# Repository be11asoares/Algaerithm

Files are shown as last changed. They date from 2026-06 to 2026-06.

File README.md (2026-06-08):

# Algaerithm — Build Your Own Pod

Algaerithm is a citizen-science river-monitoring project. A floating pod holds a
colony of microalgae (*Chlamydomonas*) in river water and watches how its colour
changes — greener water means a higher nutrient load. A small camera inside the
pod sends a photo to the cloud every few seconds, and those photos appear live on
the shared map at the project website.

This guide covers the **camera unit**: what to buy, how to flash it, and how to
get your pod's live image onto the shared Algaerithm map.

> One pod tells you about one stretch of water. A hundred pods start to tell you
> about a country. The more Guardians who join, the harder the data is to ignore.

---

## What you'll need

**Hardware**

- **Seeed Studio XIAO ESP32S3 Sense** — a tiny ESP32 board with a built-in
  camera and microSD slot. This is the board the reference pod uses.
  Search "XIAO ESP32S3 Sense" at the Seeed Studio store or any electronics
  retailer that stocks Seeed boards.
- A USB-C cable to flash and power it.
- (Optional) a microSD card if you also want to save full-resolution photos
  locally. The cloud upload works without one.
- A waterproof enclosure for the floating pod. Enclosure design is part of the
  wider project and not covered here.

**Software & accounts**

- The [Arduino IDE](https://www.arduino.cc/en/software) with ESP32 board support
  installed.
- A free [Adafruit IO](https://io.adafruit.com) account — this is the cloud
  service that receives your photos and makes them readable by the website.

---

## Step 1 — Set up Adafruit IO

Adafruit IO stores your latest photo in something called a **feed**. The website
reads that feed to show your image. You need two feeds.

1. Sign up at [io.adafruit.com](https://io.adafruit.com) (free).
2. Go to **Feeds → New Feed** and create two feeds. Name them simply:
   - `image-latest`
   - `last-photo-time`
3. **Check the feed _key_, not just the name.** Click into each feed and look at
   its **Key** (under the feed name or in its settings). The key is what the code
   and the website actually use. If you typed a dot or unusual characters in the
   name, Adafruit may turn them into something unexpected (for example a `.` can
   become `-dot-`). Make the keys clean: `image-latest` and `last-photo-time`.
4. Find your **username** (top-right account menu) and your **AIO Key**
   (the yellow key icon). You'll paste both into the code.

### ⚠️ Make both feeds Public — and keep them public

The website reads your feeds **without a password**, so they must be set to
**Public**. A public feed is still **read-only** to the world: anyone can see the
image, but only your AIO Key can upload to it. Your key stays private.

For each feed: open it → **Feed settings / privacy** → set **Public** → save.

**Confirm it worked.** Open this URL in a private/incognito window (logged out),
replacing the username and key with yours:

```
https://io.adafruit.com/api/v2/YOUR_USERNAME/feeds/image-latest
```

- If you see a block of text (JSON) including `"visibility":"public"` — you're
  good.
- If you see `{"error":"not found..."}` — the feed is still **private**. Set it
  to Public and check again.

> **This is the single most common reason a pod doesn't show up.** Adafruit's
> privacy setting can quietly flip back to private when you change other feed
> settings (especially toggling Feed History). After *any* change to a feed,
> re-check the incognito URL before relying on it.

### Turn Feed History off (recommended)

Your camera uploads constantly, and stored history fills your free quota fast.
In each feed's settings, turn **Feed History off** so it keeps only the latest
value. Then **re-check the Public setting** — toggling history can reset it.

---

## Step 2 — Flash the camera

1. Open the camera sketch (`camera_pod.ino`) in the Arduino IDE.
2. Select the **XIAO ESP32S3** board and the right port.
3. Fill in your details at the top of the sketch — these are the only lines you
   need to change:

   ```cpp
   // WiFi
   const char *ssid     = "YOUR_WIFI_NAME";
   const char *password = "YOUR_WIFI_PASSWORD";

   // Adafruit IO
   const char *aioUsername = "YOUR_USERNAME";
   const char *aioKey      = "YOUR_AIO_KEY";
   const char *aioFeedLatest = "image-latest";        // must match your feed KEY
   const char *aioFeedTime   = "last-photo-time";     // must match your feed KEY
   ```

4. Upload. Open the Serial Monitor at **115200 baud** to watch it connect.

You should see WiFi connect, then repeating lines like:

```
Capturing photo for Adafruit IO...
Upload size: 6020
Adafruit IO response code: 200
```

A **200** means success. Other codes:

- **404** — the feed key in your code doesn't match a feed on Adafruit, or the
  feed doesn't exist. Re-check the keys (Step 1.3).
- **-1** — the connection failed before completing, usually a memory squeeze from
  too large an image. Lower the resolution (see the `AIO_FRAME_SIZE` line in the
  sketch — `FRAMESIZE_HVGA` is a safe choice).

### A note on resolution

Bigger images look sharper but use more memory and can fail to upload. The sketch
uploads at a modest size on purpose. If uploads fail or the board crashes after a
few photos, step the resolution down. `FRAMESIZE_HVGA` (480×320) is a reliable
balance for the XIAO ESP32S3.

---

## Step 3 — Flash the AlgaeScope (spectrometer)

The AlgaeScope is the second board. It measures the algae's colour with an AS7341
spectral sensor and serves its own dashboard on your WiFi — no cloud account
needed for this part, and no separate app to install. The device *is* the app.

Wiring and the parts list (AS7341 sensor, white LED, ring lights, breadboard) are
on the [build page](https://algaerhythm.vercel.app/build.html). Once it's wired:

1. Open the AlgaeScope sketch (`algaescope.ino`) in the Arduino IDE.
2. Fill in your WiFi details at the top — these are the only lines to change:

   ```cpp
   const char* ssid      = "YOUR_WIFI_NAME";
   const char* password  = "YOUR_WIFI_PASSWORD";
   ```

3. Select the **XIAO ESP32S3** board and the right port, then upload.
4. Open the Serial Monitor at **115200 baud**. It connects to WiFi and prints the
   address where the dashboard is reachable.

### Reaching the dashboard

Once it's running, open a browser **on the same WiFi** and go to:

```
http://algaescope.local
```

If your network or device doesn't support `.local` addresses (some Android phones
and locked-down networks don't), use the numeric IP address the Serial Monitor
prints instead — it looks like `http://192.168.1.xx`.

The dashboard gives you live spectral readings, absorbance, the chlorophyll stress
ratio, a growth curve over time, grow-light control, and CSV export. Readings are
held in the device's memory while it's powered on.

> **Note:** reaching the device at `algaescope.local` relies on mDNS being enabled
> in the sketch. If you're using an older copy of the code, use the IP address from
> the Serial Monitor instead.

---

## Step 4 — Add your pod to the shared map

Once your camera is uploading and your feeds are public, you can have your pod
appear on the shared Algaerithm map alongside everyone else's.

**To add your pod, email us at b.soares0520251@arts.ac.uk** with the following:

| Field | Example | Notes |
|---|---|---|
| Guardian name | "Sam R." | A name we can credit on the map. |
| River / area | "River Lea · Hackney" | **Coarse area only** — your town or river reach, never your exact address. |
| Adafruit username | "sam_pods" | From your account menu. |
| Image feed key | "image-latest" | The feed **key**, exactly. |
| Timestamp feed key | "last-photo-time" | The feed **key**, exactly. |
| Both feeds public? | "Yes" | Confirm you've set both to Public (see Step 1) — we can't show your pod otherwise. |

We review each submission (mainly to confirm the feeds are public and the
location is coarse) and then add it to the map. Because we check by hand, there
may be a short wait — thanks for your patience.

> **Privacy:** please give only a coarse location — a river name and town or
> neighbourhood. The map deliberately never shows exact coordinates, so hosting a
> pod never reveals where you live.

---

## How it fits together (for the curious)

```
[ XIAO camera ]  --photo-->  [ Adafruit IO feed (public) ]  <--reads--  [ website ]
```

- The camera uploads a photo to your Adafruit feed every few seconds.
- Your feed is public, so the website can read its latest value from any browser.
- The website holds a list of all registered pods (`pods.json`) and shows a live
  card for each one.

No central server stores your images — the site reads each pod's public feed
directly. That keeps the whole thing free and simple to run.

---

## Common problems

| Symptom | Likely cause | Fix |
|---|---|-----|
| Pod doesn't appear on the site | Feed is private | Set feed to Public; confirm with the incognito URL (Step 1). |
| Serial shows `404` | Feed key mismatch | Match the code's feed names to the actual feed **keys** on Adafruit. |
| Serial shows `-1` | Image too large / low memory | Lower `AIO_FRAME_SIZE` to `FRAMESIZE_HVGA`. |
| Image shows on Adafruit but not the site | Page cached, or feed flipped private | Hard-refresh (Ctrl/Cmd+Shift+R); re-check Public setting. |
| Feed quota fills up | Feed History is on | Turn Feed History off, then re-confirm Public. |

---

## License

The code in this repository (the Arduino sketches and website) is released under
the **MIT License** — see the `LICENSE` file. You're free to use, modify, and
build on it; just keep the copyright notice.

The build documentation, designs, and project materials are shared under
**Creative Commons Attribution-ShareAlike (CC BY-SA 4.0)** — use and adapt them
freely, credit Algaerithm, and share your versions under the same terms.

*Algaerithm — MA Biodesign, Central Saint Martins, UAL.*

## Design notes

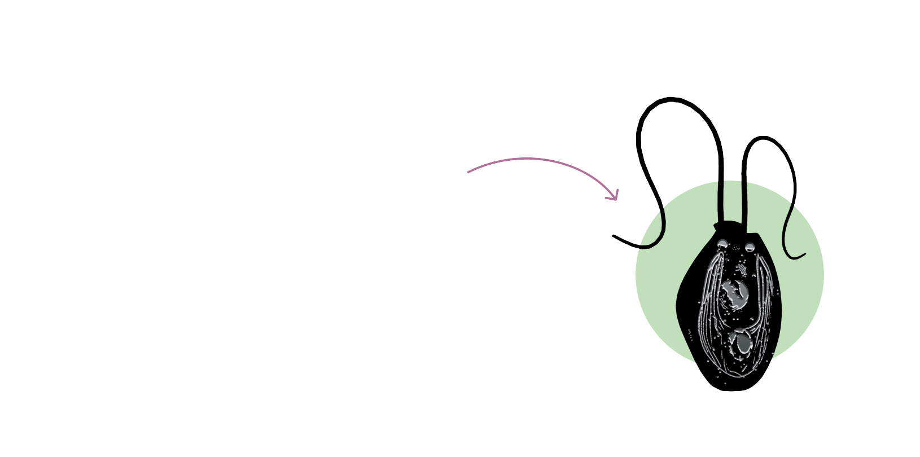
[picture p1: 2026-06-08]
chlamyy.png

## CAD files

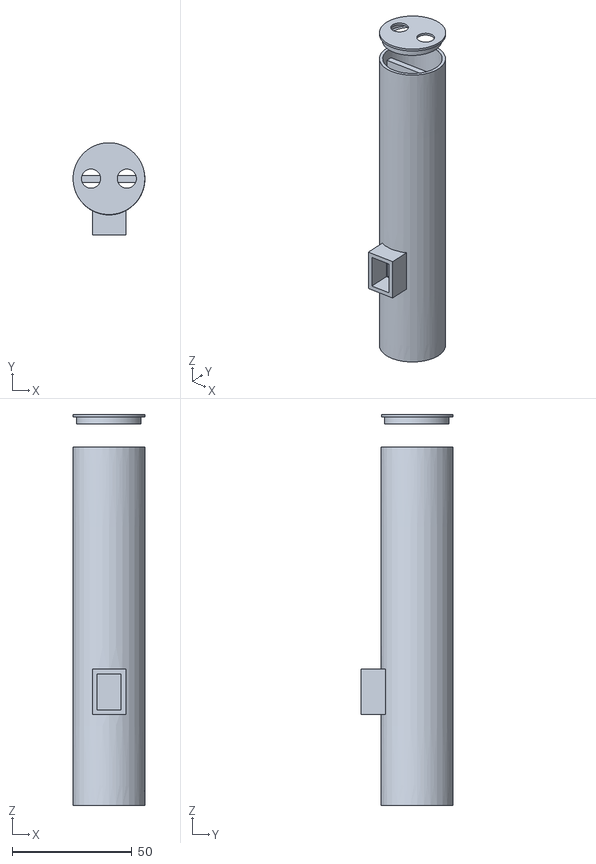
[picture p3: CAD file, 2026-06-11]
3d-files/column.stl
30.0 x 38.7 x 163.5

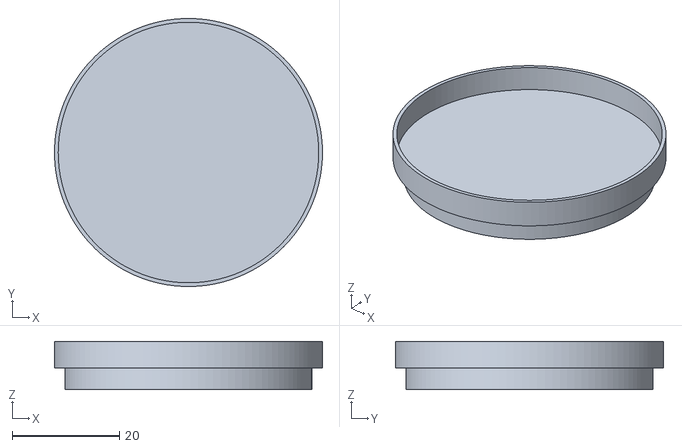
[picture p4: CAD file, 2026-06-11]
3d-files/led-support.stl
50.0 x 50.0 x 9.00

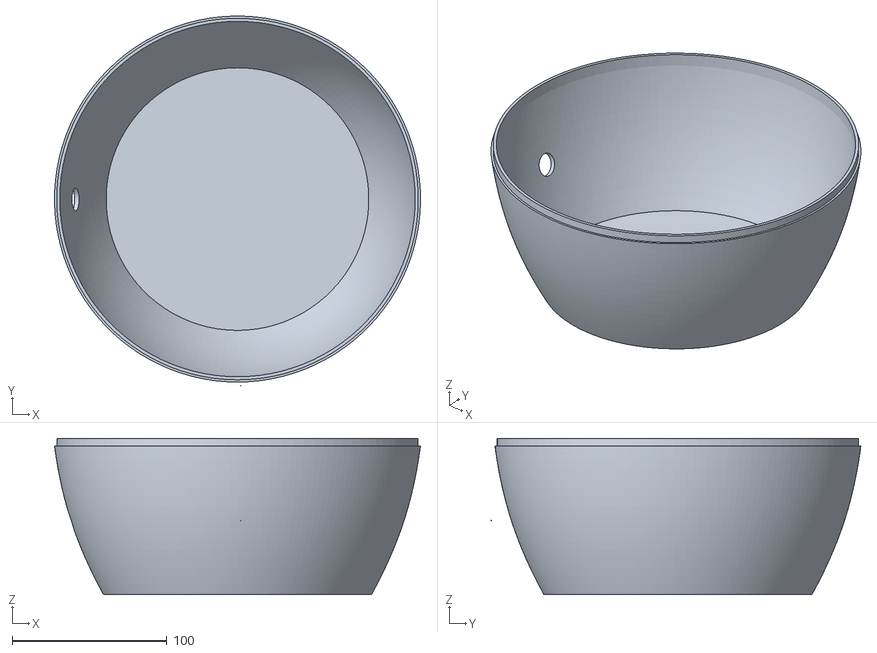
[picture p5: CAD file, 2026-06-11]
3d-files/base.stl
236.9 x 239.3 x 101.0

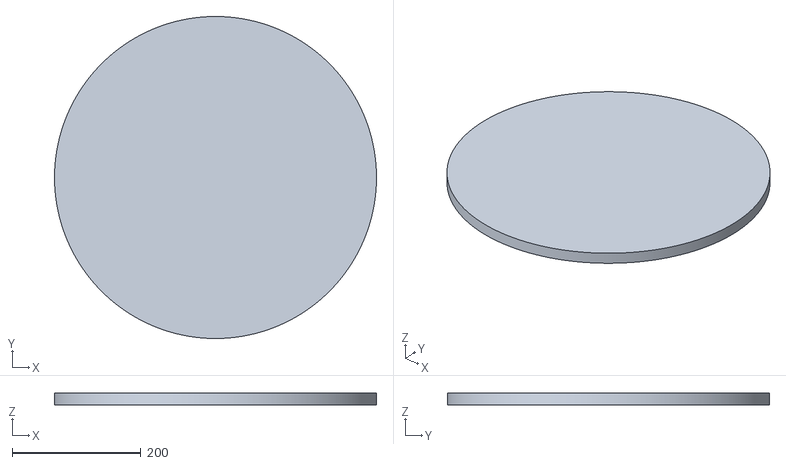
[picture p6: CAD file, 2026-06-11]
3d-files/wooden-board.stl
500.0 x 500.0 x 18.0

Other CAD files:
3d-files/pod-platform-model-with-fittings.3dm

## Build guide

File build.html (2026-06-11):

Open source · Build your own

# Build your own pod

Algaerithm is open source. Everything you need to build a floating river pod — the 3D files, the electronics, the code, and the algae protocol — is here. This page is the friendly walkthrough; every file lives on GitHub (https://github.com/be11asoares/Algaerithm) if you want the detail.

Step 1Assembly

The pod is a floating enclosure that holds a sample of river water and the electronics that watch it. Here's how to make the physical pod.

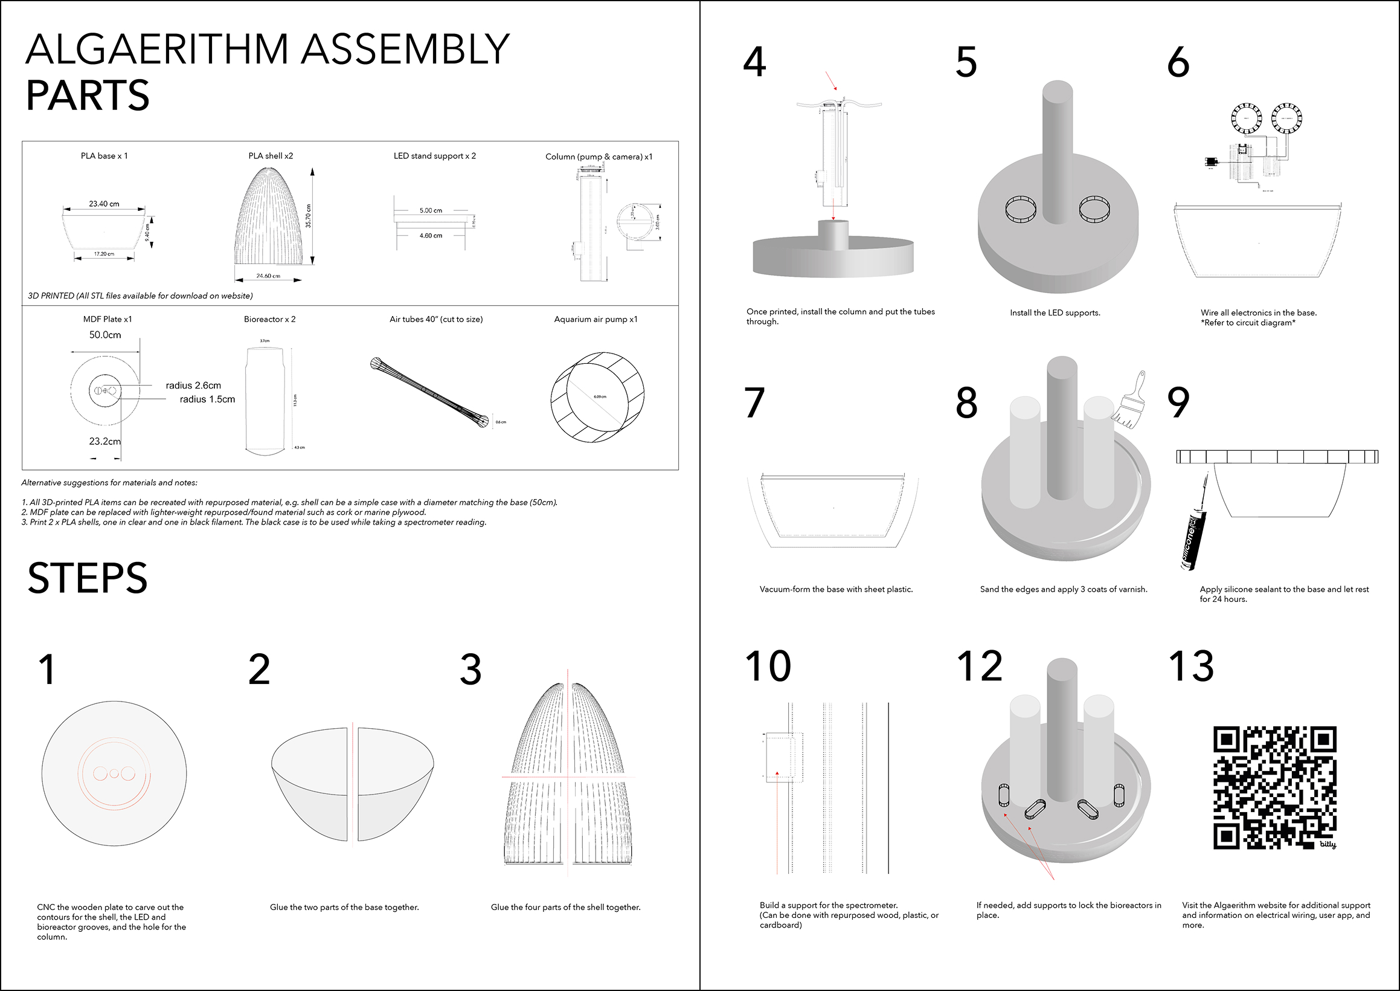
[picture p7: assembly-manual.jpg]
Algaerithm assembly manual: parts list with dimensions for the 3D-printed base, shell, LED supports and column, plus 13 numbered build steps from CNC-ing the wooden plate to wiring the electronics a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


The full assembly manual — parts, dimensions and the 13 build steps. Click to enlarge

Download assembly manual (PDF) → (https://github.com/be11asoares/Algaerithm/blob/main/pod-assembly-manual.pdf) STL files on GitHub → (https://github.com/be11asoares/Algaerithm/tree/main/3d-files) Bill of materials → (https://github.com/be11asoares/Algaerithm)

Step 2Electronics & code

Two small boards do the work: a camera unit that photographs the pod and sends the image to the cloud, and the AlgaeScope — a spectrometer that measures the algae's colour across eight wavelengths.

Camera unit: a Seeed Studio XIAO ESP32S3 Sense. It uploads a photo to a free Adafruit IO account every few seconds, which is what appears live on the map. Full setup — including the Adafruit steps and the common pitfalls — is in the GitHub README.

AlgaeScope (spectrometer): a XIAO ESP32S3 with an AS7341 spectral sensor, an OLED display, and a white LED light source. It hosts its own dashboard on your WiFi (see Step 4).

### The circuit

Here's how everything wires together — the XIAO board, the AS7341 sensor, the white measurement LED, and the two NeoPixel ring lights, all on a breadboard.

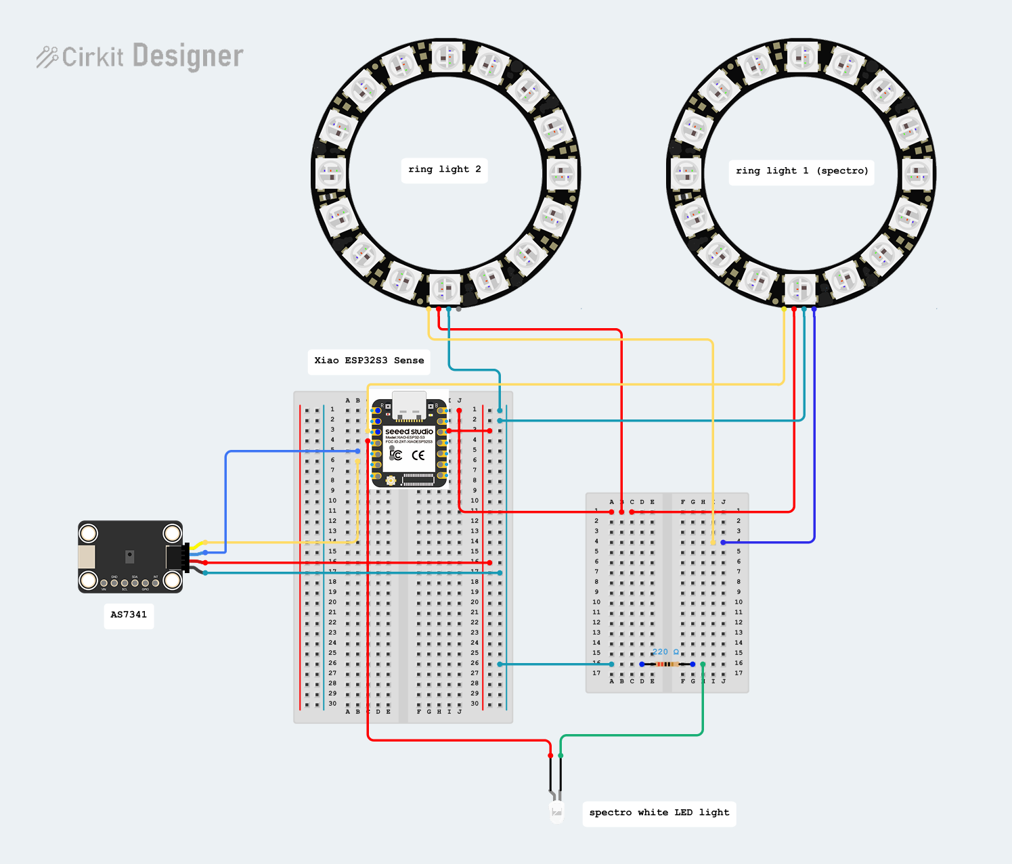
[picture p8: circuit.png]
Algaerithm circuit diagram showing the XIAO ESP32S3, AS7341 sensor, white LED and two ring lights wired on a breadboard


The full pod circuit. Built and exported with Cirkit Designer. Click here to view the circuit on Cirkit Designer → (https://app.cirkitdesigner.com/project/8b85eb68-ec11-4733-9e0b-e11b5ff70586)

### What to buy

Everything is off-the-shelf. You'll need two XIAO ESP32S3 Sense boards — one for the spectrometer, one for the camera.

Component | What it's for | Qty | Link
XIAO ESP32S3 Sense | The brains. One runs the spectrometer, one runs the camera. | 2 | The Pi Hut → (https://thepihut.com/products/seeed-studio-xiao-esp32s3-sense?variant=54885426889089)
Adafruit AS7341 sensor | 10-channel spectral sensor — reads the algae's colour. | 1 | The Pi Hut → (https://thepihut.com/products/adafruit-as7341-10-channel-light-color-sensor-breakout?variant=32380076425278)
STEMMA QT → male headers cable | Connects the AS7341 to the breadboard. | 1 | The Pi Hut → (https://thepihut.com/products/stemma-qt-qwiic-jst-sh-4-pin-to-premium-male-headers-cable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)
White 5mm LED | The measurement light source for the spectrometer. | 1 (pack of 25) | The Pi Hut → (https://thepihut.com/products/super-bright-white-5mm-led-25-pack?variant=27740488017)
Half-size breadboard | Holds the circuit together. | 1 | The Pi Hut → (https://thepihut.com/products/raspberry-pi-breadboard-half-size?variant=758602977)
NeoPixel ring lights (2×12 LED) | Grow lighting for the algae, controlled from the dashboard. | 2 | Amazon → (https://www.amazon.co.uk/gp/product/B0CMW5LWM2/)

You'll also need a 220 Ω resistor for the LED (commonly in any starter kit), basic jumper wires, and a microSD card if you want the camera to also save full-resolution photos locally.

Power To run everything untethered on the water, the pod is powered by a 20,000 mAh USB power bank — enough to keep both boards, the lights and the air pump running through a full sampling cycle.

Camera code → (https://github.com/be11asoares/Algaerithm/tree/main/camera_pod) AlgaeScope code → (https://github.com/be11asoares/Algaerithm/blob/main/algaescope.ino) Full setup guide → (https://github.com/be11asoares/Algaerithm#readme)

Step 3Inoculation of microalgae

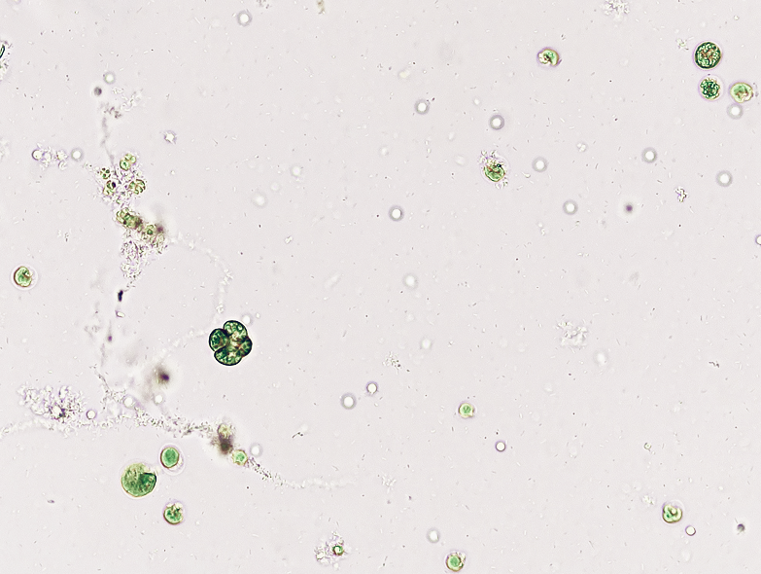
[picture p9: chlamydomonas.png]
Chlamydomonas reinhardtii microalgae culture


Chlamydomonas reinhardtii — the living sensor at the heart of the pod. Click to enlarge

The pod uses Chlamydomonas reinhardtii, a freshwater green alga, as its living sensor. You inoculate a starter culture into your river-water sample and let it grow.

### Culture & conditions

- Organism: Chlamydomonas reinhardtii
- Light: continuous, roughly 40–150 µE m⁻² s⁻¹
- Temperature: environmental (ideal around 25 °C)
- Organism-to-media ratio: 1:5

You can order the Chlamydomonas reinhardtii culture from Blades Biological (https://blades-bio.co.uk/shop/living-organisms/algae-protozoa-nematode/protozoa/chlamydomonas-large/).

### Protocol

1. Add 50 ml of a river-water sample from your chosen location.
2. Add 10 ml of Chlamydomonas reinhardtii to the pod.
3. Mix the culture thoroughly.
4. Insert the air-pump tube into the pod and close it with the air-filter enclosure provided.
5. Turn on the air pump for thorough gas exchange, and close the shell for uniform light dispersion.

Step 4The AlgaeScope app

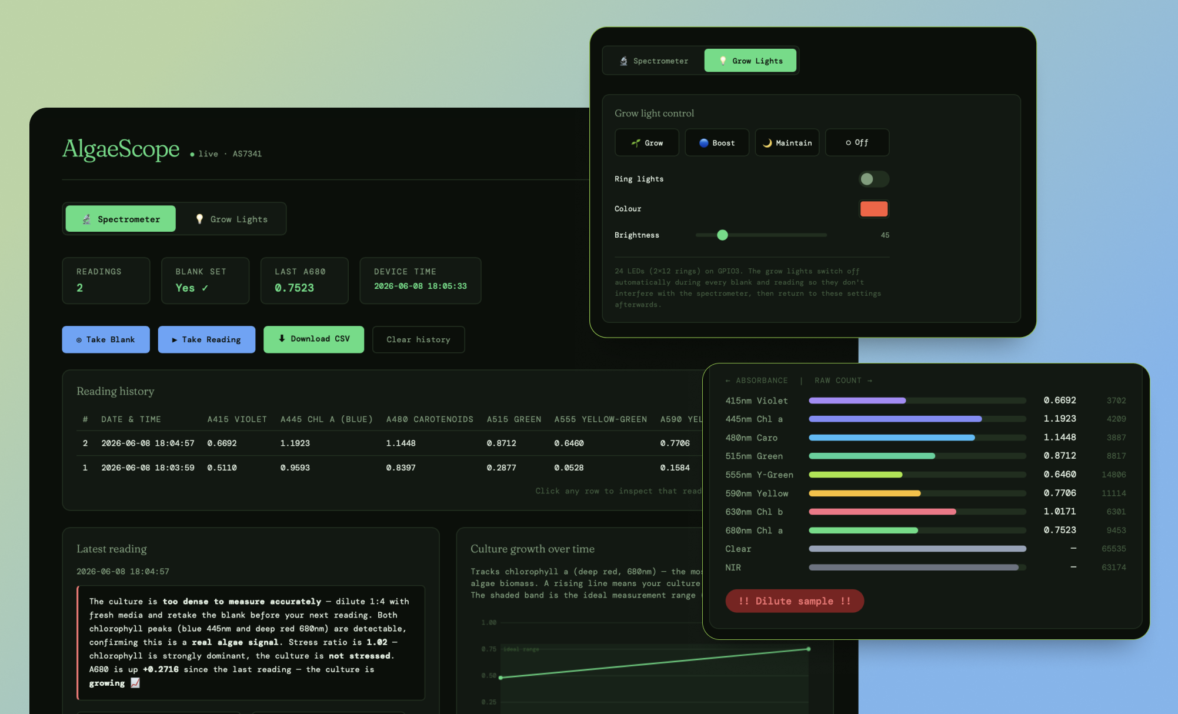
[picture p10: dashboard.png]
The AlgaeScope dashboard showing spectral readings, absorbance bars, a growth curve and grow-light controls


The AlgaeScope dashboard, served straight from the device at algaescope.local. Click to enlarge

The AlgaeScope doesn't need a separate app to install — the device is the app. When it powers on it connects to your WiFi and runs a small dashboard you open in a web browser.

1. Flash the AlgaeScope code to the board and open the Arduino Serial Monitor.
2. It connects to your WiFi and is reachable at http://algaescope.local from any browser on the same network. (If your network or device doesn't support .local addresses, use the numeric IP it prints to the Serial Monitor instead.)
3. Open that address and the dashboard appears: live spectral readings, absorbance, the stress ratio, a growth curve, grow-light control, and CSV export.

Because it runs on your local network, you view it on the same WiFi as the device — there's no public server or login. Readings are held in the device's memory while it's running.

▶ Open the live dashboard ↗

Opens in a new tab — interactive demo loaded with sample readings from a real 7-day culture, not a live pod.

AlgaeScope code → (https://github.com/be11asoares/Algaerithm/blob/main/algaescope.ino)

Step 5Reading the colour

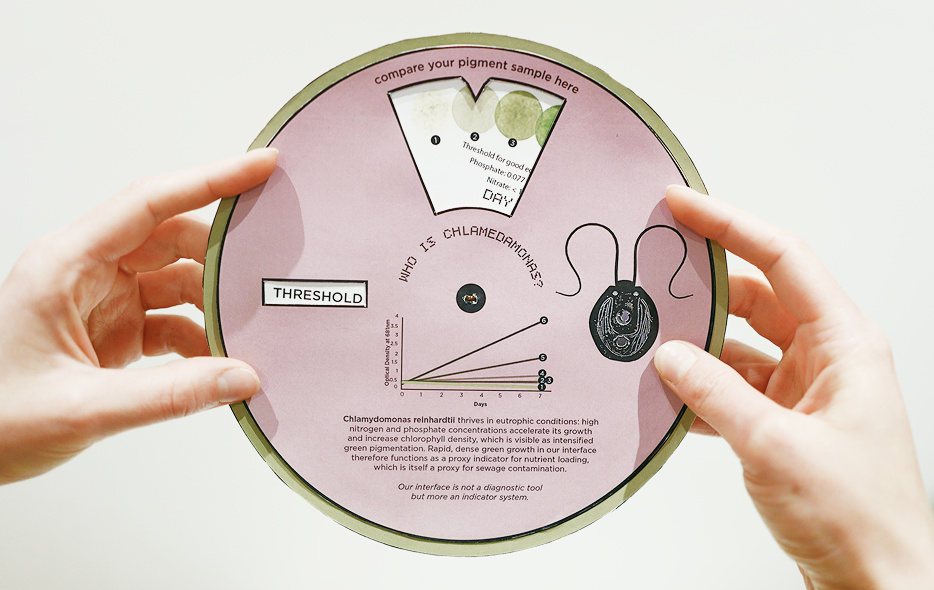
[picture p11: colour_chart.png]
Colour chart for reading algae nutrient levels


How to read the colour. Click to enlarge

Colour is the data. The greener the sample, the higher the nutrient load in the water. This chart shows how to read what you're seeing.

Add your content here — Laurie / Moukthika Drop in the colour chart and the guide to reading it: what each colour band means, the healthy vs stressed ranges, and how the spectrometer's numbers (e.g. the A590/A680 stress ratio) line up with what you see by eye.

## Built one? Add it to the map

Once your pod is streaming, email us at b.soares0520251@arts.ac.uk and we'll add it to the shared map alongside everyone else's. The more pods, the clearer the picture of our rivers becomes.

Full instructions on GitHub → (https://github.com/be11asoares/Algaerithm#readme)

Algaerithm

MA Biodesign · Central Saint Martins · UAL · 2025/26
A citizen science and biodesign project
Open source · MIT (code) & CC BY-SA (docs)

Team Ada Pejic · Bella Abrahão Soares (https://www.linkedin.com/in/bella-soares/) · Christine Weng · Jenny Wang (https://www.linkedin.com/in/jing-jenny-wang-b1283a210/) · Laurie Camelot · Moukthika Pinnamreddy (https://www.linkedin.com/in/moukthika-pinnamreddy/)

Results indicate nutrient load potential. Not a drinking or bathing water safety assessment.

×

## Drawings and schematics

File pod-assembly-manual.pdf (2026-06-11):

# ALGAERITHM ASSEMBLY

# PARTS

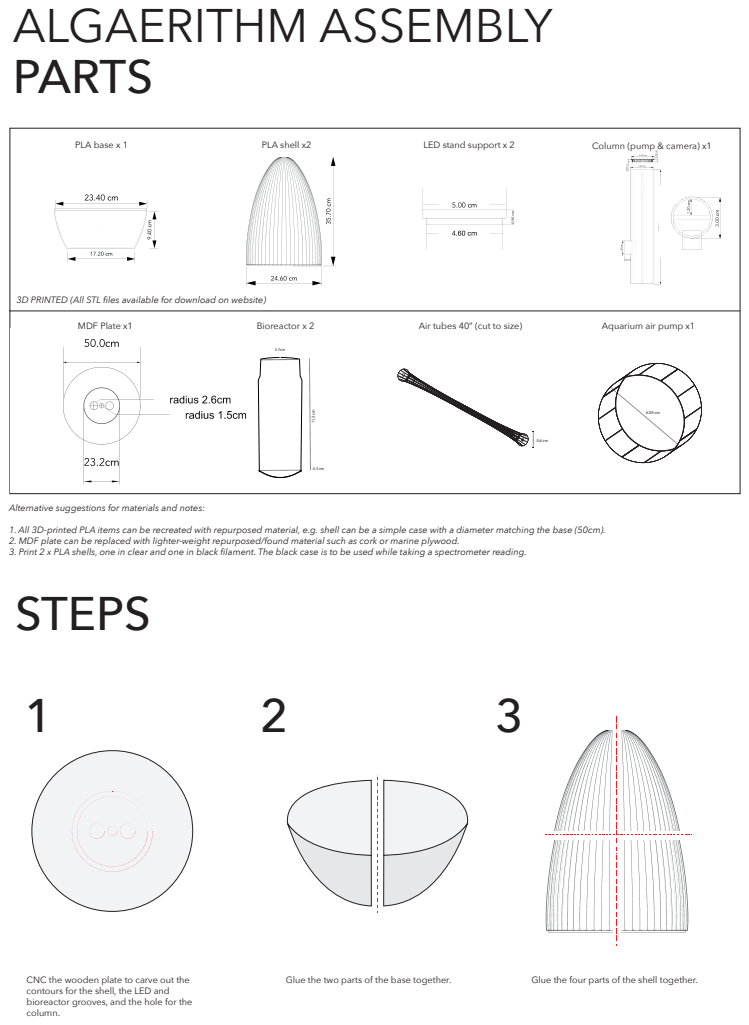
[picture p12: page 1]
PLA base x 1; MDF Plate x1; Bioreactor x 2; PLA shell x2; LED stand support x 2; Glue the two parts of the base together.; Glue the four parts of the shell together.

Column (pump & camera) x1

3D PRINTED (All STL files available for download on website)

Air tubes 40” (cut to size)

Aquarium air pump x1

Alternative suggestions for materials and notes:
1. All 3D-printed PLA items can be recreated with repurposed material, e.g. shell can be a simple case with a diameter matching the base (50cm).
2. MDF plate can be replaced with lighter-weight repurposed/found material such as cork or marine plywood.
3. Print 2 x PLA shells, one in clear and one in black filament. The black case is to be used while taking a spectrometer reading.
STEPS

CNC the wooden plate to carve out the
contours for the shell, the LED and
bioreactor grooves, and the hole for the
column.

4 | 5 | 6

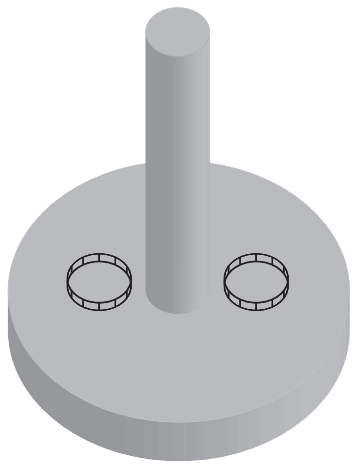
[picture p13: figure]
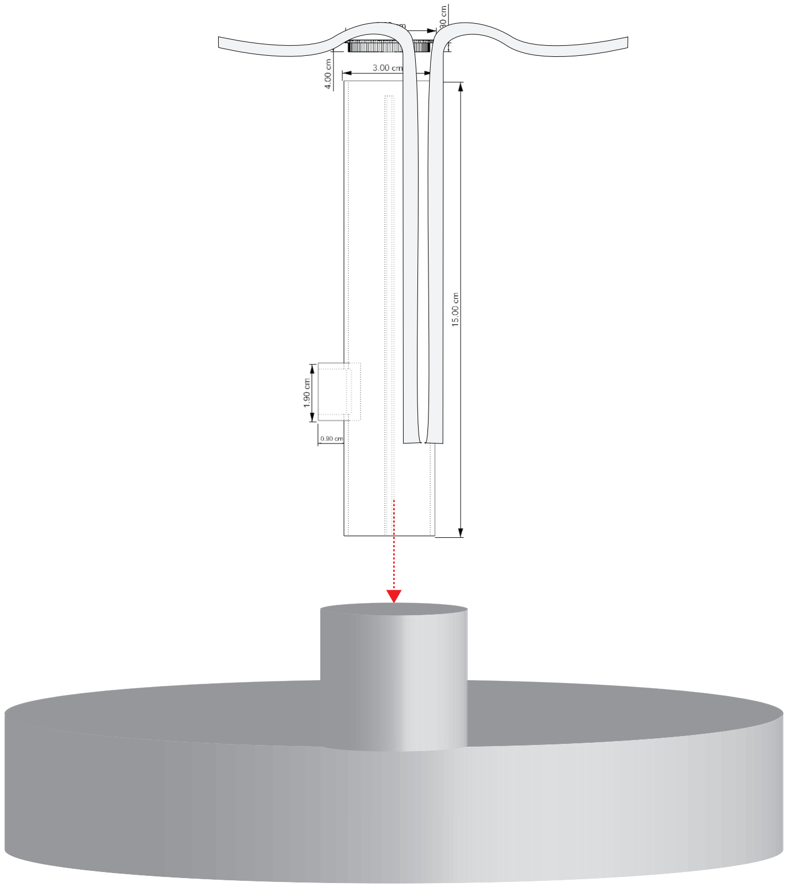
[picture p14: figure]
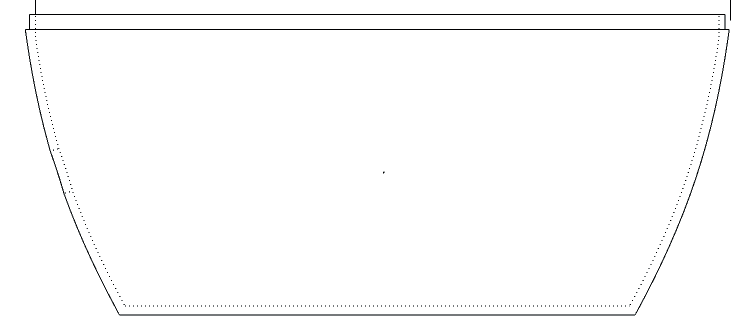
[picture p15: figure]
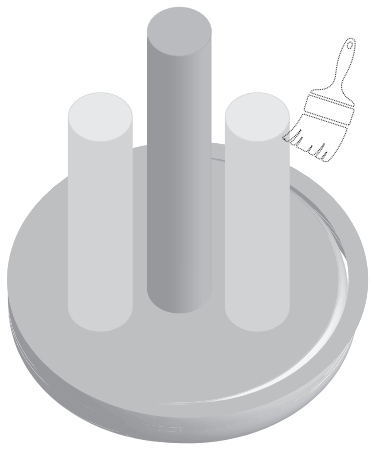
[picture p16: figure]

7 | 8 | 9
10 | 12 | 13

Once printed, install the column and put the tubes
through.

Vacuum-form the base with sheet plastic.

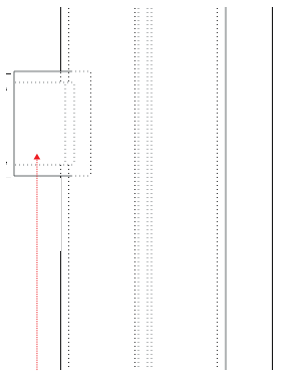
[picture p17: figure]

Build a support for the spectrometer.
(Can be done with repurposed wood, plastic, or cardboard)

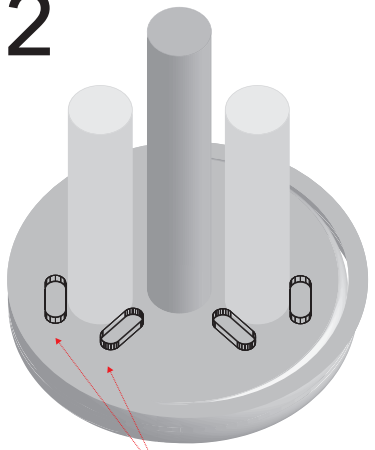
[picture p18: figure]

If needed, add supports to lock the bioreactors in place.

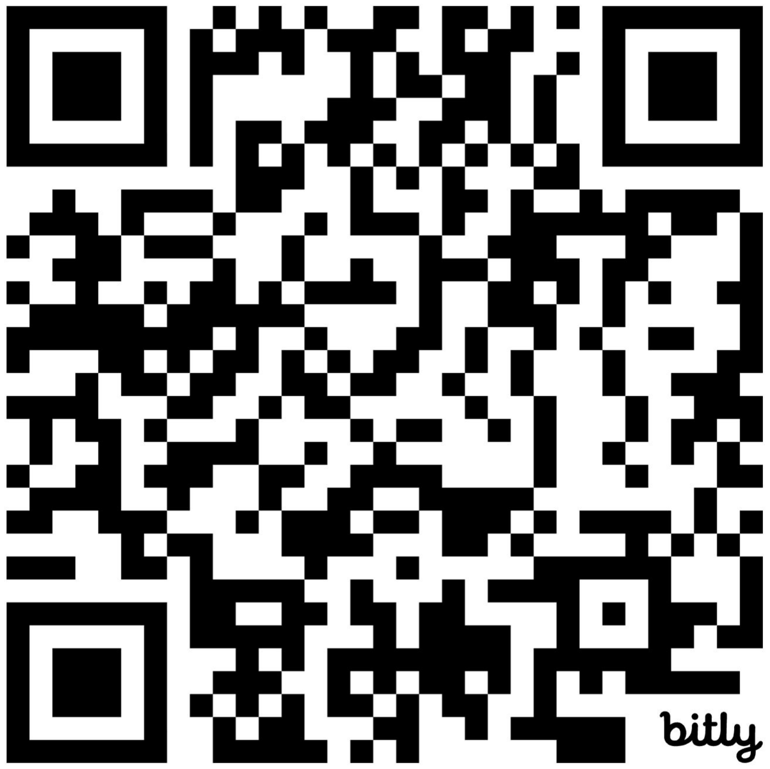
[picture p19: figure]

Visit the Algaerithm website for additional support and information on electrical wiring, user app, and more.

Sand the edges and apply 3 coats of varnish. | Apply silicone sealant to the base and let rest for 24 hours.
Install the LED supports. | Wire all electronics in the base. *Refer to circuit diagram*

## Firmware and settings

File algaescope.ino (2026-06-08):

#include <Adafruit_AS7341.h>
#include <Adafruit_SSD1306.h>
#include <Adafruit_NeoPixel.h>
#include <Wire.h>
#include <WiFi.h>
#include <WebServer.h>
#include <ArduinoJson.h>
#include <time.h>

// ── Config ────────────────────────────────────────────────────────────────────
#define SCREEN_WIDTH   128
#define SCREEN_HEIGHT  64
#define OLED_RESET     -1
#define SCREEN_ADDRESS 0x3C
#define NUM_AVERAGES   5
#define BTN_BLANK      1
#define BTN_READING    2
#define MAX_READINGS   100

// LED ring + spectrometer light
#define RING_PIN       3      // WS2812 data line (2x12 chained = 24 LEDs)
#define RING_COUNT     24
#define SPEC_LED_PIN   4      // white spectrometer LED — MOVE LED +ve leg from 3V3 to GPIO4 (keep 220R)
#define SPEC_SETTLE_MS 120    // let LED stabilise before measuring

const char* ssid      = "YOUR_WIFI_NAME";
const char* password  = "YOUR_WIFI_PASSWORD";
const char* ntpServer = "pool.ntp.org";
const char* timezone  = "GMT0BST,M3.5.0/1,M10.5.0";

// ── Globals ───────────────────────────────────────────────────────────────────
Adafruit_AS7341  as7341;
Adafruit_SSD1306 display(SCREEN_WIDTH, SCREEN_HEIGHT, &Wire, OLED_RESET);
Adafruit_NeoPixel ring(RING_COUNT, RING_PIN, NEO_GRB + NEO_KHZ800);
WebServer        server(80);

float blankRef[12] = {0};
bool  hasBlank     = false;
bool  timeReady    = false;

// Grow-light state (persisted in RAM, restored after each measurement)
bool    lightsOn         = false;
uint8_t lightR           = 255;
uint8_t lightG           = 255;
uint8_t lightB           = 255;
uint8_t lightBrightness  = 120;   // 0–255

struct Reading {
  char     datetime[24];
  float    A415, A445, A480, A515, A555, A590, A630, A680;
  uint16_t raw[12];
  bool     valid;
};

Reading history[MAX_READINGS];
int historyCount = 0;

// Forward declarations
void  takeBlank();
void  takeReading();
bool  getAveragedReading(uint16_t avg[12]);
void  printBar(const char* label, uint16_t value);
float calcAbsorbance(float sample, float blank);
void  printAbsorbance(const char* label, float sample, float blank);
void  applyLights();
void  ringsOff();

void getDatetime(char* buf, int len) {
  if (!timeReady) { snprintf(buf, len, "No time sync"); return; }
  struct tm timeinfo;
  if (!getLocalTime(&timeinfo)) { snprintf(buf, len, "Time error"); return; }
  strftime(buf, len, "%Y-%m-%d %H:%M:%S", &timeinfo);
}

// ── LED ring helpers ──────────────────────────────────────────────────────────
void applyLights() {
  ring.setBrightness(lightBrightness);
  if (lightsOn) {
    digitalWrite(SPEC_LED_PIN, LOW);   // rings on => spectrometer LED must be off
    for (int i = 0; i < RING_COUNT; i++) ring.setPixelColor(i, ring.Color(lightR, lightG, lightB));
  } else {
    ring.clear();
  }
  ring.show();
}

void ringsOff() {
  ring.clear();
  ring.show();
}

// ── Measurement interlock ─────────────────────────────────────────────────────
// Rings OFF, spectrometer LED ON, measure, LED OFF, restore rings.
void beginMeasurementLight() {
  ringsOff();                       // kill grow lights so they don't pollute the reading
  digitalWrite(SPEC_LED_PIN, HIGH); // spectrometer light on
  delay(SPEC_SETTLE_MS);
}

void endMeasurementLight() {
  digitalWrite(SPEC_LED_PIN, LOW);  // spectrometer light off
  applyLights();                    // restore whatever the grow lights were doing
}

// ── Webpage ───────────────────────────────────────────────────────────────────
const char webpage[] PROGMEM = R"rawhtml(
<!DOCTYPE html>
<html lang="en">
<head>
<meta charset="UTF-8">
<meta name="viewport" content="width=device-width, initial-scale=1.0">
<title>AlgaeScope</title>
<style>
  @import url('https://fonts.googleapis.com/css2?family=DM+Mono:wght@400;500&family=Fraunces:opsz,wght@9..144,300;9..144,600&display=swap');

  :root {
    --bg:      #0a0f0a;
    --surface: #111811;
    --border:  #1e2e1e;
    --green:   #4ade80;
    --yellow:  #facc15;
    --red:     #f87171;
    --blue:    #60a5fa;
    --muted:   #3d5c3d;
    --text:    #e2f0e2;
    --subtext: #7a9e7a;
    --hover:   #1a2e1a;
    --selected:#162616;
  }

  * { box-sizing: border-box; margin: 0; padding: 0; }

  body {
    background: var(--bg);
    color: var(--text);
    font-family: 'DM Mono', monospace;
    min-height: 100vh;
    padding: 2rem;
    max-width: 1200px;
    margin: 0 auto;
  }

  header {
    display: flex;
    align-items: center;
    justify-content: space-between;
    margin-bottom: 2rem;
    border-bottom: 1px solid var(--border);
    padding-bottom: 1.5rem;
  }

  .header-left { display: flex; align-items: baseline; gap: 1rem; }

  h1 {
    font-family: 'Fraunces', serif;
    font-size: 2.2rem;
    font-weight: 300;
    color: var(--green);
    letter-spacing: -0.03em;
  }

  .subtitle { color: var(--subtext); font-size: 0.75rem; }

  .guide-btn {
    font-family: 'DM Mono', monospace;
    font-size: 0.75rem;
    padding: 0.5rem 1rem;
    border-radius: 6px;
    border: 1px solid var(--border);
    background: transparent;
    color: var(--subtext);
    cursor: pointer;
    transition: all 0.15s;
    display: flex;
    align-items: center;
    gap: 0.4rem;
  }
  .guide-btn:hover { border-color: var(--green); color: var(--green); }

  /* ── Mode toggle ─────────────────────────────────────────── */
  .mode-toggle {
    display: inline-flex;
    background: var(--surface);
    border: 1px solid var(--border);
    border-radius: 8px;
    padding: 0.25rem;
    margin-bottom: 2rem;
    gap: 0.25rem;
  }
  .mode-toggle button {
    font-family: 'DM Mono', monospace;
    font-size: 0.8rem;
    padding: 0.55rem 1.4rem;
    border-radius: 6px;
    border: none;
    background: transparent;
    color: var(--subtext);
    cursor: pointer;
    transition: all 0.15s;
  }
  .mode-toggle button.active {
    background: var(--green);
    color: #0a0f0a;
    font-weight: 500;
  }

  .view { display: none; }
  .view.active { display: block; }

  .status-bar { display: flex; gap: 1rem; margin-bottom: 2rem; flex-wrap: wrap; }

  .stat {
    background: var(--surface);
    border: 1px solid var(--border);
    border-radius: 8px;
    padding: 0.75rem 1.25rem;
    min-width: 130px;
  }

  .stat-label {
    font-size: 0.65rem;
    color: var(--subtext);
    text-transform: uppercase;
    letter-spacing: 0.1em;
    margin-bottom: 0.3rem;
  }

  .stat-value { font-size: 1rem; font-weight: 500; color: var(--green); }

  .grid {
    display: grid;
    grid-template-columns: 1fr 1fr;
    gap: 1.5rem;
    margin-bottom: 1.5rem;
  }

  @media (max-width: 700px) {
    .grid { grid-template-columns: 1fr; }
    body  { padding: 1rem; }
  }

  .card {
    background: var(--surface);
    border: 1px solid var(--border);
    border-radius: 12px;
    padding: 1.25rem;
    margin-bottom: 1.5rem;
  }

  .card h2 {
    font-family: 'Fraunces', serif;
    font-size: 1rem;
    font-weight: 300;
    color: var(--subtext);
    margin-bottom: 1rem;
  }

  .card-title-row {
    display: flex;
    align-items: baseline;
    justify-content: space-between;
    margin-bottom: 1rem;
  }

  .card-title-row h2 { margin-bottom: 0; }

  .viewing-label {
    font-size: 0.65rem;
    color: var(--subtext);
    font-style: italic;
  }

  .summary-box {
    background: var(--bg);
    border: 1px solid var(--border);
    border-left: 3px solid var(--green);
    border-radius: 6px;
    padding: 0.85rem 1rem;
    margin-bottom: 1rem;
    font-size: 0.75rem;
    line-height: 1.7;
    color: var(--text);
  }

  .summary-box.warn  { border-left-color: var(--yellow); }
  .summary-box.alert { border-left-color: var(--red); }
  .summary-box.low   { border-left-color: var(--blue); }

  .inline-stats {
    display: flex;
    gap: 1rem;
    margin-bottom: 1rem;
    flex-wrap: wrap;
  }

  .inline-stat {
    background: var(--bg);
    border: 1px solid var(--border);
    border-radius: 6px;
    padding: 0.5rem 0.85rem;
    font-size: 0.7rem;
  }

  .inline-stat-label {
    color: var(--subtext);
    font-size: 0.6rem;
    text-transform: uppercase;
    letter-spacing: 0.08em;
    margin-bottom: 0.2rem;
  }

  .inline-stat-value { color: var(--text); font-weight: 500; }

  .trend-up   { color: var(--green); }
  .trend-down { color: var(--red); }
  .trend-flat { color: var(--subtext); }

  .channel {
    display: flex;
    align-items: center;
    gap: 0.75rem;
    margin-bottom: 0.55rem;
    position: relative;
  }

  .channel-label {
    font-size: 0.7rem;
    color: var(--subtext);
    width: 95px;
    flex-shrink: 0;
    cursor: help;
  }

  .bar-track {
    flex: 1; height: 8px;
    background: var(--border);
    border-radius: 4px;
    overflow: visible;
    position: relative;
  }

  .bar-fill { height: 100%; border-radius: 4px; transition: width 0.5s ease; }

  .channel-value { font-size: 0.72rem; color: var(--text); width: 52px; text-align: right; }
  .channel-raw   { font-size: 0.65rem; color: var(--muted); width: 52px; text-align: right; }

  .tooltip {
    display: none;
    position: absolute;
    left: 0;
    top: 120%;
    background: #1a2e1a;
    border: 1px solid var(--border);
    border-radius: 6px;
    padding: 0.6rem 0.8rem;
    font-size: 0.68rem;
    color: var(--text);
    line-height: 1.5;
    width: 240px;
    z-index: 100;
    pointer-events: none;
    box-shadow: 0 4px 16px rgba(0,0,0,0.4);
  }

  .tooltip strong { color: var(--green); display: block; margin-bottom: 0.2rem; }
  .channel:hover .tooltip { display: block; }

  .density {
    display: inline-block;
    padding: 0.4rem 1rem;
    border-radius: 20px;
    font-size: 0.8rem;
    font-weight: 500;
    margin-top: 0.75rem;
  }
  .density.ok     { background: #14532d; color: var(--green); }
  .density.dense  { background: #713f12; color: var(--yellow); }
  .density.dilute { background: #7f1d1d; color: var(--red); }
  .density.low    { background: #1e3a5f; color: var(--blue); }

  canvas { width: 100%; height: 200px; display: block; }

  .table-wrap { overflow-x: auto; }

  table { width: 100%; border-collapse: collapse; font-size: 0.68rem; }

  th {
    color: var(--subtext);
    text-align: left;
    padding: 0.5rem 0.6rem;
    border-bottom: 1px solid var(--border);
    font-weight: 400;
    text-transform: uppercase;
    letter-spacing: 0.07em;
    font-size: 0.6rem;
    white-space: nowrap;
  }

  td {
    padding: 0.45rem 0.6rem;
    border-bottom: 1px solid var(--border);
    color: var(--text);
    white-space: nowrap;
  }

  tr:last-child td { border-bottom: none; }
  tbody tr { cursor: pointer; transition: background 0.1s; }
  tbody tr:hover td { background: var(--hover); }
  tbody tr.selected td { background: var(--selected); border-left: 2px solid var(--green); }
  tbody tr.selected td:first-child { padding-left: calc(0.6rem - 2px); }

  .pill {
    display: inline-block;
    padding: 0.15rem 0.5rem;
    border-radius: 10px;
    font-size: 0.62rem;
  }
  .pill.ok     { background: #14532d; color: var(--green); }
  .pill.dense  { background: #713f12; color: var(--yellow); }
  .pill.dilute { background: #7f1d1d; color: var(--red); }
  .pill.low    { background: #1e3a5f; color: var(--blue); }

  .actions { display: flex; gap: 0.75rem; margin-bottom: 1.5rem; flex-wrap: wrap; }

  button {
    font-family: 'DM Mono', monospace;
    font-size: 0.75rem;
    padding: 0.6rem 1.25rem;
    border-radius: 6px;
    border: 1px solid var(--border);
    cursor: pointer;
    transition: all 0.15s;
  }

  .btn-primary   { background: var(--green); color: #0a0f0a; border-color: var(--green); font-weight: 500; }
  .btn-primary:hover   { opacity: 0.85; }
  .btn-secondary { background: transparent; color: var(--subtext); }
  .btn-secondary:hover { border-color: var(--subtext); color: var(--text); }
  .btn-measure   { background: var(--blue); color: #0a0f0a; border-color: var(--blue); font-weight: 500; }
  .btn-measure:hover { opacity: 0.85; }
  button:disabled { opacity: 0.4; cursor: not-allowed; }

  .live-dot {
    display: inline-block;
    width: 6px; height: 6px;
    background: var(--green);
    border-radius: 50%;
    margin-right: 0.4rem;
    animation: pulse 2s infinite;
  }

  @keyframes pulse { 0%,100%{opacity:1} 50%{opacity:0.3} }

  .no-data { color: var(--muted); font-size: 0.8rem; text-align: center; padding: 2rem; }

  .click-hint {
    font-size: 0.62rem;
    color: var(--muted);
    margin-top: 0.5rem;
    text-align: right;
  }

  .toast {
    position: fixed;
    bottom: 1.5rem; left: 50%;
    transform: translateX(-50%) translateY(150%);
    background: var(--surface);
    border: 1px solid var(--green);
    color: var(--green);
    padding: 0.7rem 1.4rem;
    border-radius: 8px;
    font-size: 0.78rem;
    z-index: 2000;
    transition: transform 0.3s ease;
    box-shadow: 0 6px 24px rgba(0,0,0,0.5);
  }
  .toast.show { transform: translateX(-50%) translateY(0); }
  .toast.busy { border-color: var(--blue); color: var(--blue); }

  /* ── Grow light controls ─────────────────────────────────── */
  .light-controls { display: flex; flex-direction: column; gap: 1.25rem; max-width: 460px; }

  .light-presets { display: flex; gap: 0.6rem; flex-wrap: wrap; margin-bottom: 0.25rem; }
  .preset-btn {
    flex: 1; min-width: 90px;
    font-family: 'DM Mono', monospace;
    font-size: 0.78rem;
    padding: 0.7rem 0.5rem;
    border-radius: 8px;
    border: 1px solid var(--border);
    background: var(--bg);
    color: var(--text);
    cursor: pointer;
    transition: all 0.15s;
  }
  .preset-btn:hover { border-color: var(--green); color: var(--green); }
  .preset-btn.off:hover { border-color: var(--subtext); color: var(--subtext); }

  .light-row { display: flex; align-items: center; justify-content: space-between; gap: 1rem; }

  .light-label { font-size: 0.78rem; color: var(--text); }

  .switch { position: relative; width: 52px; height: 28px; flex-shrink: 0; }
  .switch input { opacity: 0; width: 0; height: 0; }
  .slider-sw {
    position: absolute; inset: 0;
    background: var(--border);
    border-radius: 28px;
    cursor: pointer;
    transition: 0.2s;
  }
  .slider-sw::before {
    content: ''; position: absolute;
    height: 20px; width: 20px; left: 4px; bottom: 4px;
    background: var(--subtext); border-radius: 50%; transition: 0.2s;
  }
  .switch input:checked + .slider-sw { background: #14532d; }
  .switch input:checked + .slider-sw::before { transform: translateX(24px); background: var(--green); }

  input[type=range] {
    -webkit-appearance: none; appearance: none;
    width: 220px; height: 6px;
    background: var(--border); border-radius: 4px; outline: none;
  }
  input[type=range]::-webkit-slider-thumb {
    -webkit-appearance: none; appearance: none;
    width: 18px; height: 18px; border-radius: 50%;
    background: var(--green); cursor: pointer;
  }
  input[type=range]::-moz-range-thumb {
    width: 18px; height: 18px; border-radius: 50%;
    background: var(--green); cursor: pointer; border: none;
  }
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
void loop() {
  server.handleClient();

  if (Serial.available()) {
    char cmd = Serial.read();
    if (cmd == 'b') takeBlank();
    else if (cmd == 'r') takeReading();
  }

  if (digitalRead(BTN_BLANK) == LOW) {
    delay(50);
    if (digitalRead(BTN_BLANK) == LOW) {
      takeBlank();
      while (digitalRead(BTN_BLANK) == LOW) { delay(10); }
    }
  }

  if (digitalRead(BTN_READING) == LOW) {
    delay(50);
    if (digitalRead(BTN_READING) == LOW) {
      takeReading();
      while (digitalRead(BTN_READING) == LOW) { delay(10); }
    }
  }
}

// ── Averaged reading ──────────────────────────────────────────────────────────
bool getAveragedReading(uint16_t avg[12]) {
  uint32_t sums[12] = {0};
  for (int i = 0; i < NUM_AVERAGES; i++) {
    uint16_t readings[12];
    if (!as7341.readAllChannels(readings)) {
      Serial.println("Read error, retrying...");
      i--; delay(100); continue;
    }
    for (int ch = 0; ch < 12; ch++) sums[ch] += readings[ch];
    delay(20);
  }
  for (int ch = 0; ch < 12; ch++) avg[ch] = sums[ch] / NUM_AVERAGES;
  return true;
}

// ── Blank ─────────────────────────────────────────────────────────────────────
void takeBlank() {
  Serial.println("\nTaking blank...");
  display.clearDisplay(); display.setCursor(0,0);
  display.println("Taking blank..."); display.display();

  beginMeasurementLight();        // rings off, spectrometer LED on
  uint16_t avg[12];
  bool ok = getAveragedReading(avg);
  endMeasurementLight();          // spectrometer LED off, rings restored
  if (!ok) return;

  for (int ch = 0; ch < 12; ch++) blankRef[ch] = avg[ch];
  hasBlank = true;

  Serial.println("=== Blank Saved ===");
  printBar("415nm violet ", avg[0]);  printBar("445nm blue   ", avg[1]);
  printBar("480nm cyan   ", avg[2]);  printBar("515nm green  ", avg[3]);
  printBar("555nm y-green", avg[6]);  printBar("590nm yellow ", avg[7]);
  printBar("630nm red    ", avg[8]);  printBar("680nm deepRed", avg[9]);
  printBar("Clear        ", avg[10]); printBar("NIR          ", avg[11]);
  Serial.println("-----------------------------");
  Serial.println("Blank saved.");

  display.clearDisplay(); display.setCursor(0,0);
  display.println("Blank saved!");
  display.println("");
  display.print("Clear: "); display.println(avg[10]);
  display.print("680nm: "); display.println(avg[9]);
  display.println(""); display.println("Take reading on web");
  display.display();
}

// ── Reading ───────────────────────────────────────────────────────────────────
void takeReading() {
  Serial.println("\nTaking reading...");
  display.clearDisplay(); display.setCursor(0,0);
  display.println("Taking reading..."); display.display();

  beginMeasurementLight();        // rings off, spectrometer LED on
  uint16_t avg[12];
  bool ok = getAveragedReading(avg);
  endMeasurementLight();          // spectrometer LED off, rings restored
  if (!ok) return;

  Serial.println("=== Reading ===");
  printBar("415nm violet ", avg[0]);  printBar("445nm blue   ", avg[1]);
  printBar("480nm cyan   ", avg[2]);  printBar("515nm green  ", avg[3]);
  printBar("555nm y-green", avg[6]);  printBar("590nm yellow ", avg[7]);
  printBar("630nm red    ", avg[8]);  printBar("680nm deepRed", avg[9]);
  printBar("Clear        ", avg[10]); printBar("NIR          ", avg[11]);
  Serial.println("-----------------------------");

  if (!hasBlank) {
    Serial.println("No blank set — take a blank first");
    display.clearDisplay(); display.setCursor(0,0);
    display.println("No blank set!"); display.println("Take blank on web");
    display.display(); return;
  }

  float A415 = calcAbsorbance(avg[0],  blankRef[0]);
  float A445 = calcAbsorbance(avg[1],  blankRef[1]);
  float A480 = calcAbsorbance(avg[2],  blankRef[2]);
  float A515 = calcAbsorbance(avg[3],  blankRef[3]);
  float A555 = calcAbsorbance(avg[6],  blankRef[6]);
  float A590 = calcAbsorbance(avg[7],  blankRef[7]);
  float A630 = calcAbsorbance(avg[8],  blankRef[8]);
  float A680 = calcAbsorbance(avg[9],  blankRef[9]);

  Serial.println("=== Absorbance vs Blank ===");
  printAbsorbance("415nm violet  ", avg[0],  blankRef[0]);
  printAbsorbance("445nm (Chl a) ", avg[1],  blankRef[1]);
  printAbsorbance("480nm (Caro)  ", avg[2],  blankRef[2]);
  printAbsorbance("515nm green   ", avg[3],  blankRef[3]);
  printAbsorbance("555nm y-green ", avg[6],  blankRef[6]);
  printAbsorbance("590nm yellow  ", avg[7],  blankRef[7]);
  printAbsorbance("630nm (Chl b) ", avg[8],  blankRef[8]);
  printAbsorbance("680nm (Chl a) ", avg[9],  blankRef[9]);
  Serial.println("-----------------------------");

  float stress = (A680 > 0.1) ? A590 / A680 : 0;
  if (A680 > 0.1) {
    Serial.print("Stress ratio (A590/A680): "); Serial.println(stress, 4);
  } else {
    Serial.println("Stress ratio: n/a (A680 too low)");
  }

  if (A680>1.0||A445>1.0)      Serial.println("!! DILUTE SAMPLE !!");
  else if (A680>0.6||A445>0.8) Serial.println("Sample is dense — consider diluting");
  else if (A680<0.05)          Serial.println("Very low density");
  else                         Serial.println("Density: OK");
  Serial.println("-----------------------------");

  if (historyCount < MAX_READINGS) {
    Reading& r = history[historyCount++];
    getDatetime(r.datetime, sizeof(r.datetime));
    r.A415=A415; r.A445=A445; r.A480=A480; r.A515=A515;
    r.A555=A555; r.A590=A590; r.A630=A630; r.A680=A680;
    for (int ch = 0; ch < 12; ch++) r.raw[ch] = avg[ch];
    r.valid = true;
    Serial.print("Saved at: "); Serial.println(r.datetime);
  }

  display.clearDisplay(); display.setCursor(0,0);
  display.println("== Absorbance ==");
  display.print("680 Chl a: "); display.println(A680, 4);
  display.print("445 Chl a: "); display.println(A445, 4);
  display.print("630 Chl b: "); display.println(A630, 4);
  if (A680 > 0.1) {
    display.print("Stress:    "); display.println(stress, 2);
  } else {
    display.println("Stress:    n/a");
  }
  display.println("");
  if (A680>1.0||A445>1.0)      display.println("!! DILUTE SAMPLE !!");
  else if (A680>0.6||A445>0.8) { display.println("Dense — consider"); display.println("diluting"); }
  else if (A680<0.05)          display.println("Very low density");
  else                         display.println("Density: OK");
  display.display();
}

// ── Helpers ───────────────────────────────────────────────────────────────────
void printBar(const char* label, uint16_t value) {
  Serial.print(label); Serial.print(" | ");
  int bars = map(value, 0, 65535, 0, 40);
  for (int i=0; i<bars; i++) Serial.print("#");
  Serial.print(" "); Serial.println(value);
}

float calcAbsorbance(float sample, float blank) {
  if (blank<=0||sample<=0) return 0;
  return -log10(sample/blank);
}

void printAbsorbance(const char* label, float sample, float blank) {
  float A = calcAbsorbance(sample, blank);
  Serial.print(label);
  Serial.print(" A="); Serial.print(A, 4);
  Serial.print("  T="); Serial.print((sample/blank)*100.0, 1);
  Serial.println("%");
}

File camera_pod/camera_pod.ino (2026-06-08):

#include <Arduino.h>
#include "esp_camera.h"
#include <WiFi.h>
#include "time.h"
#include <HTTPClient.h>
#include <WiFiClientSecure.h>
#include "mbedtls/base64.h"

#include "board_config.h"

// WiFi
const char *ssid     = "YOUR_WIFI_NAME";
const char *password = "YOUR_WIFI_PASSWORD";

// Adafruit IO
const char *aioUsername   = "YOUR_AIO_USERNAME";
const char *aioKey        = "YOUR_AIO_KEY";
const char *aioFeedLatest = "presentation.image-latest";
const char *aioFeedTime   = "presentation.last-photo-time";

// UK time
const char* ntpServer          = "pool.ntp.org";
const long  gmtOffset_sec      = 0;
const int   daylightOffset_sec = 3600;

// Resolution for upload
#define AIO_FRAME_SIZE  FRAMESIZE_HVGA

// Non-blocking 10-second timer
unsigned long lastPhotoMillis = 0;
const unsigned long PHOTO_INTERVAL = 10000;  // 10 seconds

String serialBuffer = "";

void startCameraServer();
void setupLedFlash();

// -----------------------------------------------------------------------
const char* ordinalSuffix(int day) {
  if (day >= 11 && day <= 13) return "th";
  switch (day % 10) {
    case 1:  return "st";
    case 2:  return "nd";
    case 3:  return "rd";
    default: return "th";
  }
}

void uploadTimestamp() {
  struct tm timeinfo;
  if (!getLocalTime(&timeinfo)) {
    Serial.println("uploadTimestamp: could not get time");
    return;
  }

  char monthYear[20];
  strftime(monthYear, sizeof(monthYear), "%B, %Y", &timeinfo);
  char hourMin[10];
  strftime(hourMin, sizeof(hourMin), "%H:%M", &timeinfo);

  char ts[50];
  snprintf(ts, sizeof(ts), "%d%s %s @ %s",
    timeinfo.tm_mday,
    ordinalSuffix(timeinfo.tm_mday),
    monthYear,
    hourMin);

  String url = "https://io.adafruit.com/api/v2/";
  url += aioUsername;
  url += "/feeds/";
  url += aioFeedTime;
  url += "/data";

  WiFiClientSecure client;
  client.setInsecure();
  HTTPClient http;
  http.begin(client, url);
  http.addHeader("Content-Type", "application/json");
  http.addHeader("X-AIO-Key", aioKey);

  String payload = "{\"value\":\"";
  payload += ts;
  payload += "\"}";

  int httpCode = http.POST(payload);
  Serial.print("Timestamp upload response: ");
  Serial.println(httpCode);
  http.end();
}

// -----------------------------------------------------------------------
// Builds the JSON body directly into one malloc'd buffer to avoid
// holding the image in memory multiple times over.
bool uploadPhotoToAdafruitIO(camera_fb_t *fb, const char *feedName) {
  Serial.println("Preparing image upload to Adafruit IO...");

  // Work out base64 length
  size_t b64Len = 0;
  mbedtls_base64_encode(NULL, 0, &b64Len, fb->buf, fb->len);

  // Buffer = {"value":"<base64>"}  +  null terminator
  const char *prefix = "{\"value\":\"";
  const char *suffix = "\"}";
  size_t prefixLen = strlen(prefix);
  size_t suffixLen = strlen(suffix);
  size_t totalLen  = prefixLen + (b64Len - 1) + suffixLen + 1; // b64Len includes its own null

  char *body = (char *)malloc(totalLen);
  if (!body) {
    Serial.println("Body malloc failed");
    return false;
  }

  // Assemble: prefix + base64 + suffix
  memcpy(body, prefix, prefixLen);
  size_t written = 0;
  if (mbedtls_base64_encode((unsigned char *)(body + prefixLen),
                            b64Len, &written, fb->buf, fb->len) != 0) {
    Serial.println("Base64 encode failed");
    free(body);
    return false;
  }
  // written includes the null terminator position; overwrite from there
  memcpy(body + prefixLen + written, suffix, suffixLen);
  body[prefixLen + written + suffixLen] = '\0';

  size_t bodyLen = prefixLen + written + suffixLen;

  String url = "https://io.adafruit.com/api/v2/";
  url += aioUsername;
  url += "/feeds/";
  url += feedName;
  url += "/data";

  WiFiClientSecure client;
  client.setInsecure();
  HTTPClient http;
  http.begin(client, url);
  http.addHeader("Content-Type", "application/json");
  http.addHeader("X-AIO-Key", aioKey);

  Serial.print("Upload size: ");
  Serial.println(bodyLen);

  int httpCode = http.POST((uint8_t *)body, bodyLen);
  Serial.print("Adafruit IO response code: ");
  Serial.println(httpCode);
  http.end();

  free(body);
  return httpCode > 0 && httpCode < 300;
}

void captureAndUpload() {
  Serial.printf("Free heap: %u | Largest block: %u\n",
                ESP.getFreeHeap(), ESP.getMaxAllocHeap());
  Serial.println("Capturing photo for Adafruit IO...");
  camera_fb_t *fb = esp_camera_fb_get();
  if (!fb) {
    Serial.println("Camera capture failed");
    return;
  }

  uploadPhotoToAdafruitIO(fb, aioFeedLatest);
  esp_camera_fb_return(fb);   // return frame ASAP, before timestamp upload

  uploadTimestamp();
}

void setup() {
  Serial.begin(115200);
  Serial.setDebugOutput(true);
  Serial.println();

  camera_config_t config;
  config.ledc_channel = LEDC_CHANNEL_0;
  config.ledc_timer   = LEDC_TIMER_0;
  config.pin_d0       = Y2_GPIO_NUM;
  config.pin_d1       = Y3_GPIO_NUM;
  config.pin_d2       = Y4_GPIO_NUM;
  config.pin_d3       = Y5_GPIO_NUM;
  config.pin_d4       = Y6_GPIO_NUM;
  config.pin_d5       = Y7_GPIO_NUM;
  config.pin_d6       = Y8_GPIO_NUM;
  config.pin_d7       = Y9_GPIO_NUM;
  config.pin_xclk     = XCLK_GPIO_NUM;
  config.pin_pclk     = PCLK_GPIO_NUM;
  config.pin_vsync    = VSYNC_GPIO_NUM;
  config.pin_href     = HREF_GPIO_NUM;
  config.pin_sccb_sda = SIOD_GPIO_NUM;
  config.pin_sccb_scl = SIOC_GPIO_NUM;
  config.pin_pwdn     = PWDN_GPIO_NUM;
  config.pin_reset    = RESET_GPIO_NUM;
  config.xclk_freq_hz = 20000000;
  config.frame_size   = AIO_FRAME_SIZE;
  config.pixel_format = PIXFORMAT_JPEG;
  config.grab_mode    = CAMERA_GRAB_WHEN_EMPTY;
  config.fb_location  = CAMERA_FB_IN_PSRAM;
  config.jpeg_quality = 12;
  config.fb_count     = 1;

  if (psramFound()) {
    config.fb_count  = 2;
    config.grab_mode = CAMERA_GRAB_LATEST;
  } else {
    Serial.println("WARNING: PSRAM not found.");
    config.fb_location = CAMERA_FB_IN_DRAM;
  }

  esp_err_t err = esp_camera_init(&config);
  if (err != ESP_OK) {
    Serial.printf("Camera init failed with error 0x%x", err);
    return;
  }

  sensor_t *s = esp_camera_sensor_get();
  if (s->id.PID == OV3660_PID) {
    s->set_vflip(s, 1);
    s->set_brightness(s, 1);
    s->set_saturation(s, -2);
  }

#if defined(LED_GPIO_NUM)
  setupLedFlash();
#endif

  WiFi.begin(ssid, password);
  WiFi.setSleep(false);
  Serial.print("WiFi connecting");
  while (WiFi.status() != WL_CONNECTED) {
    delay(500);
    Serial.print(".");
  }
  Serial.println("\nWiFi connected");

  configTime(gmtOffset_sec, daylightOffset_sec, ntpServer);
  struct tm timeinfo;
  if (!getLocalTime(&timeinfo)) {
    Serial.println("Failed to obtain time");
  } else {
    Serial.println("Time obtained");
  }

  startCameraServer();
  Serial.print("Camera Ready! Use 'http://");
  Serial.print(WiFi.localIP());
  Serial.println("' to connect");

  captureAndUpload();
  lastPhotoMillis = millis();

  Serial.println("Ready! Streaming every 10 seconds. Type 'snap' for a manual photo.");
}
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
